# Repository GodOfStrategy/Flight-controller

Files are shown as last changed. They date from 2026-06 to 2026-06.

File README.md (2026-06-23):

# Flight-controller
A custom Flight controller to control a rocket with TVC! It uses a STM32 and other peripherals like power management, battery charging etc. to make it a fully functional controller, with LiPo support.
This is my schematic{1A992728-89DA-410E-9264-2D571C69BAF3}
This is how my PCB looks:{BEE2E16C-D04B-4341-9590-978375379D45}
This how my Assembled PCB is supposed to look like:{85D26635-DA95-49A9-963A-9BCFD05A4956}
{B8652330-A4F8-4AD3-A79F-0697AFAC499F}
This is my BoM (also in a .csv file in the repo): 
[bom.csv](https://github.com/user-attachments/files/29258043/bom.csv)

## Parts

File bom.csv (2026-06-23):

Designator | Footprint | Value |  | Generic-Name | Qty | Source | Total Price ($) | Product link
C1 | 0402 | 47 nF |  | Capacitors | 20 | 20 JLCPCB | 0.068 | https://jlcpcb.com/partdetail/83376-0402B473K500NT/C82219
C2,C3 | 0402 | 22 uF |  |  | 20 | 20 JLCPCB | 0.394 | https://jlcpcb.com/partdetail/16204-CL05A106MQ5NUNC/C15525
C4 | 0805 | 10 uf |  |  | 5 | 5 JLCPCB | 1.0915 | https://jlcpcb.com/partdetail/125403-GRM21BR61A476ME15L/C124129
C10,C11,C16,C17,C9 | 0805 | 100 nF |  |  | 18 | 18 JLCPCB | 2.1114 | https://jlcpcb.com/partdetail/46786-CL21A226MAQNNNE/C45783
C12,C13,C14,C5,C8 | 0805 | 10 uF |  |  | 10 | 10 JLCPCB | 0.912 | https://jlcpcb.com/partdetail/439567-GRM21BR61H106KE43L/C440198
C15,C18,C19,C20,C21,C26,C28,C29,C30,C31,C32,C7 | 0402 | 20 pF |  |  | 34 | 34 JLCPCB | 0.204 | https://jlcpcb.com/partdetail/1877-CL05B104KO5NNNC/C1525
C22,C23 | 0402 | 6.8 pF |  |  | 20 | 20 JLCPCB | 0.066 | https://jlcpcb.com/partdetail/1906-0402CG200J500NT/C1554
C24,C25 | 0402 | 2.2 uF |  |  | 20 | 20 JLCPCB | 0.048 | https://jlcpcb.com/partdetail/1928-0402CG6R8C500NT/C1576
C27 | 0402 | 1 uF |  |  | 20 | 20 JLCPCB | 0.154 | https://jlcpcb.com/partdetail/13164-CL05A225MQ5NSNC/C12530
C33,C34,C35,C36,C6 | 0402 | 44 uF |  |  | 20 | 20 JLCPCB | 0.282 | https://jlcpcb.com/partdetail/53938-CL05A105KA5NQNC/C52923
CARD1 | SMD | TF-01A | C91145 | SD Card Slot | 2 | 2 JLCPCB | 0.3802 | https://jlcpcb.com/partdetail/Korean_HropartsElec-TF01A/C91145
D1 | 0805 | LED |  | LED | 20 | 20 JLCPCB | 0.244 | https://jlcpcb.com/partdetail/Hubei_KENTOElec-KT0805B/C2293
J1 | 插件,P=2.54mm | Screw_Terminal_01x02 |  | Screw Terminal | 2 | 2 JLCPCB | 0.48 | https://jlcpcb.com/partdetail/Ningbo_Xinlaiya_Elec-XY308_2_542P/C557685
L1 | 1210 | 1 uH |  |  | 6 | 6 JLCPCB | 0.696 | https://jlcpcb.com/partdetail/100626-CMI322513U1R0KT/C99412
L2 | 1008 | 1.5 uH |  | Inductors | 6 | 6 JLCPCB | 0.2256 | https://jlcpcb.com/partdetail/XR-XRNR252010_1_5uHN/C5289259
L3 | 1210 | 5.6uH |  |  | 6 | 6 JLCPCB | 0.2748 | https://jlcpcb.com/partdetail/TDK-NLV32T_5R6JPF/C87563
L4 | 0603 | FCM1608KF-601T03 | C141723 | Ferrite Bead | 20 | 20 JLCPCB | 0.202 | https://jlcpcb.com/partdetail/TAITECH-FCM1608KF601T03/C141723
R1,R2 | 0402 | 5.1K |  | Resistors | 20 | 20 JLCPCB | 0.018 | https://jlcpcb.com/partdetail/26648-0402WGF5101TCE/C25905
R9 | 0201 | 30.1K |  |  | 20 | 20 JLCPCB | 0.012 | https://jlcpcb.com/partdetail/301723-RC01W3012FT/C320818
R10 | 0201 | 383 |  |  | 20 | 20 JLCPCB | 0.012 | https://jlcpcb.com/partdetail/416501-0201WMF3830TEE/C423551
R11 | 0201 | 5.23K |  |  | 20 | 20 JLCPCB | 0.022 | https://jlcpcb.com/partdetail/RALEC-RTT015231FTH/C332546
R12,R13,R16,R17,R18,R19,R20,R21,R22,R3,R4,R5,R6,R7,R8 | 0201 | 10K |  |  | 40 | 40 JLCPCB | 0.032 | https://jlcpcb.com/partdetail/FOJAN-FRC0201J103TS/C7467266
R14 | 0805 | 100K |  |  | 20 | 20 JLCPCB | 0.064 | https://jlcpcb.com/partdetail/160838-0805W8F1003T5E/C149504
R15 | 0201 | 22.1K |  |  | 20 | 20 JLCPCB | 0.02 | https://jlcpcb.com/partdetail/Walsin_TechCorp-WR02X2212FAL/C384418
SW1,SW2 | SMD,4x3mm | TS-1088-AR02016 |  | Switches | 8 | 8 JLCPCB | 0.4408 | https://jlcpcb.com/partdetail/XUNPU-TS_1088AR02016/C720477
U1 | VQFN-24-EP(4x4) | BQ25883RGER | C720477 | battery Management | 2 | 2 JLCPCB | 8.189 | https://jlcpcb.com/partdetail/TexasInstruments-BQ25883RGER/C544362
U2 | VQFN-15-HR(2.5x3) | TPS63070RNMR | C544362 | Buck convertor (5V) | 2 | 2 JLCPCB | 2.6384 | https://jlcpcb.com/partdetail/TexasInstruments-TPS63070RNMR/C109322
U3 | SOT-23-6-THIN(DDC) | LMR51430 | C109322 | Buck convertor | 2 | 2 JLCPCB | 1.73 | https://jlcpcb.com/partdetail/TexasInstruments-LMR51430YFDDCR/C5219261
U4 | LGA-10(2x2) | BMP580 |  | Barometer | 2 | 2 JLCPCB | 2.6674 | https://jlcpcb.com/partdetail/BoschSensortec-BMP580/C22391138
U5 | LGA-14(3x2.5) | ICM-45686 | C22391138 | IMU | 2 | 2 JLCPCB | 25.8362 | https://jlcpcb.com/partdetail/TDKInvenSense-ICM45686/C22459454
U6 | LQFP-64(10x10) | STM32F722RETx | C22459454 | MCU | 2 | 2 JLCPCB | 12.522 | https://jlcpcb.com/partdetail/STMicroelectronics-STM32F722RET6/C118207
USB1 | SMD | TYPE-C16PIN2MD |  | USB-C | 3 | 3 JLCPCB | 0.2205 | https://jlcpcb.com/partdetail/SHOUHAN-TYPE_C_16PIN_2MD_073/C2765186
X1 | SMD3225-4P | X322525MOB4SI | C2765186 | 25 MHz Quartz Crystal | 6 | 6 JLCPCB | 0.618 | https://jlcpcb.com/partdetail/YXC_CrystalOscillators-X322525MOB4SI/C9006
X2 | SMD3215-2P | Q13FC1350000400 | C9006 | 32.768 KHz Quartz Crystal | 5 | 5 JLCPCB | 0.8635 | https://jlcpcb.com/partdetail/SeikoEpson-Q13FC13500004/C32346

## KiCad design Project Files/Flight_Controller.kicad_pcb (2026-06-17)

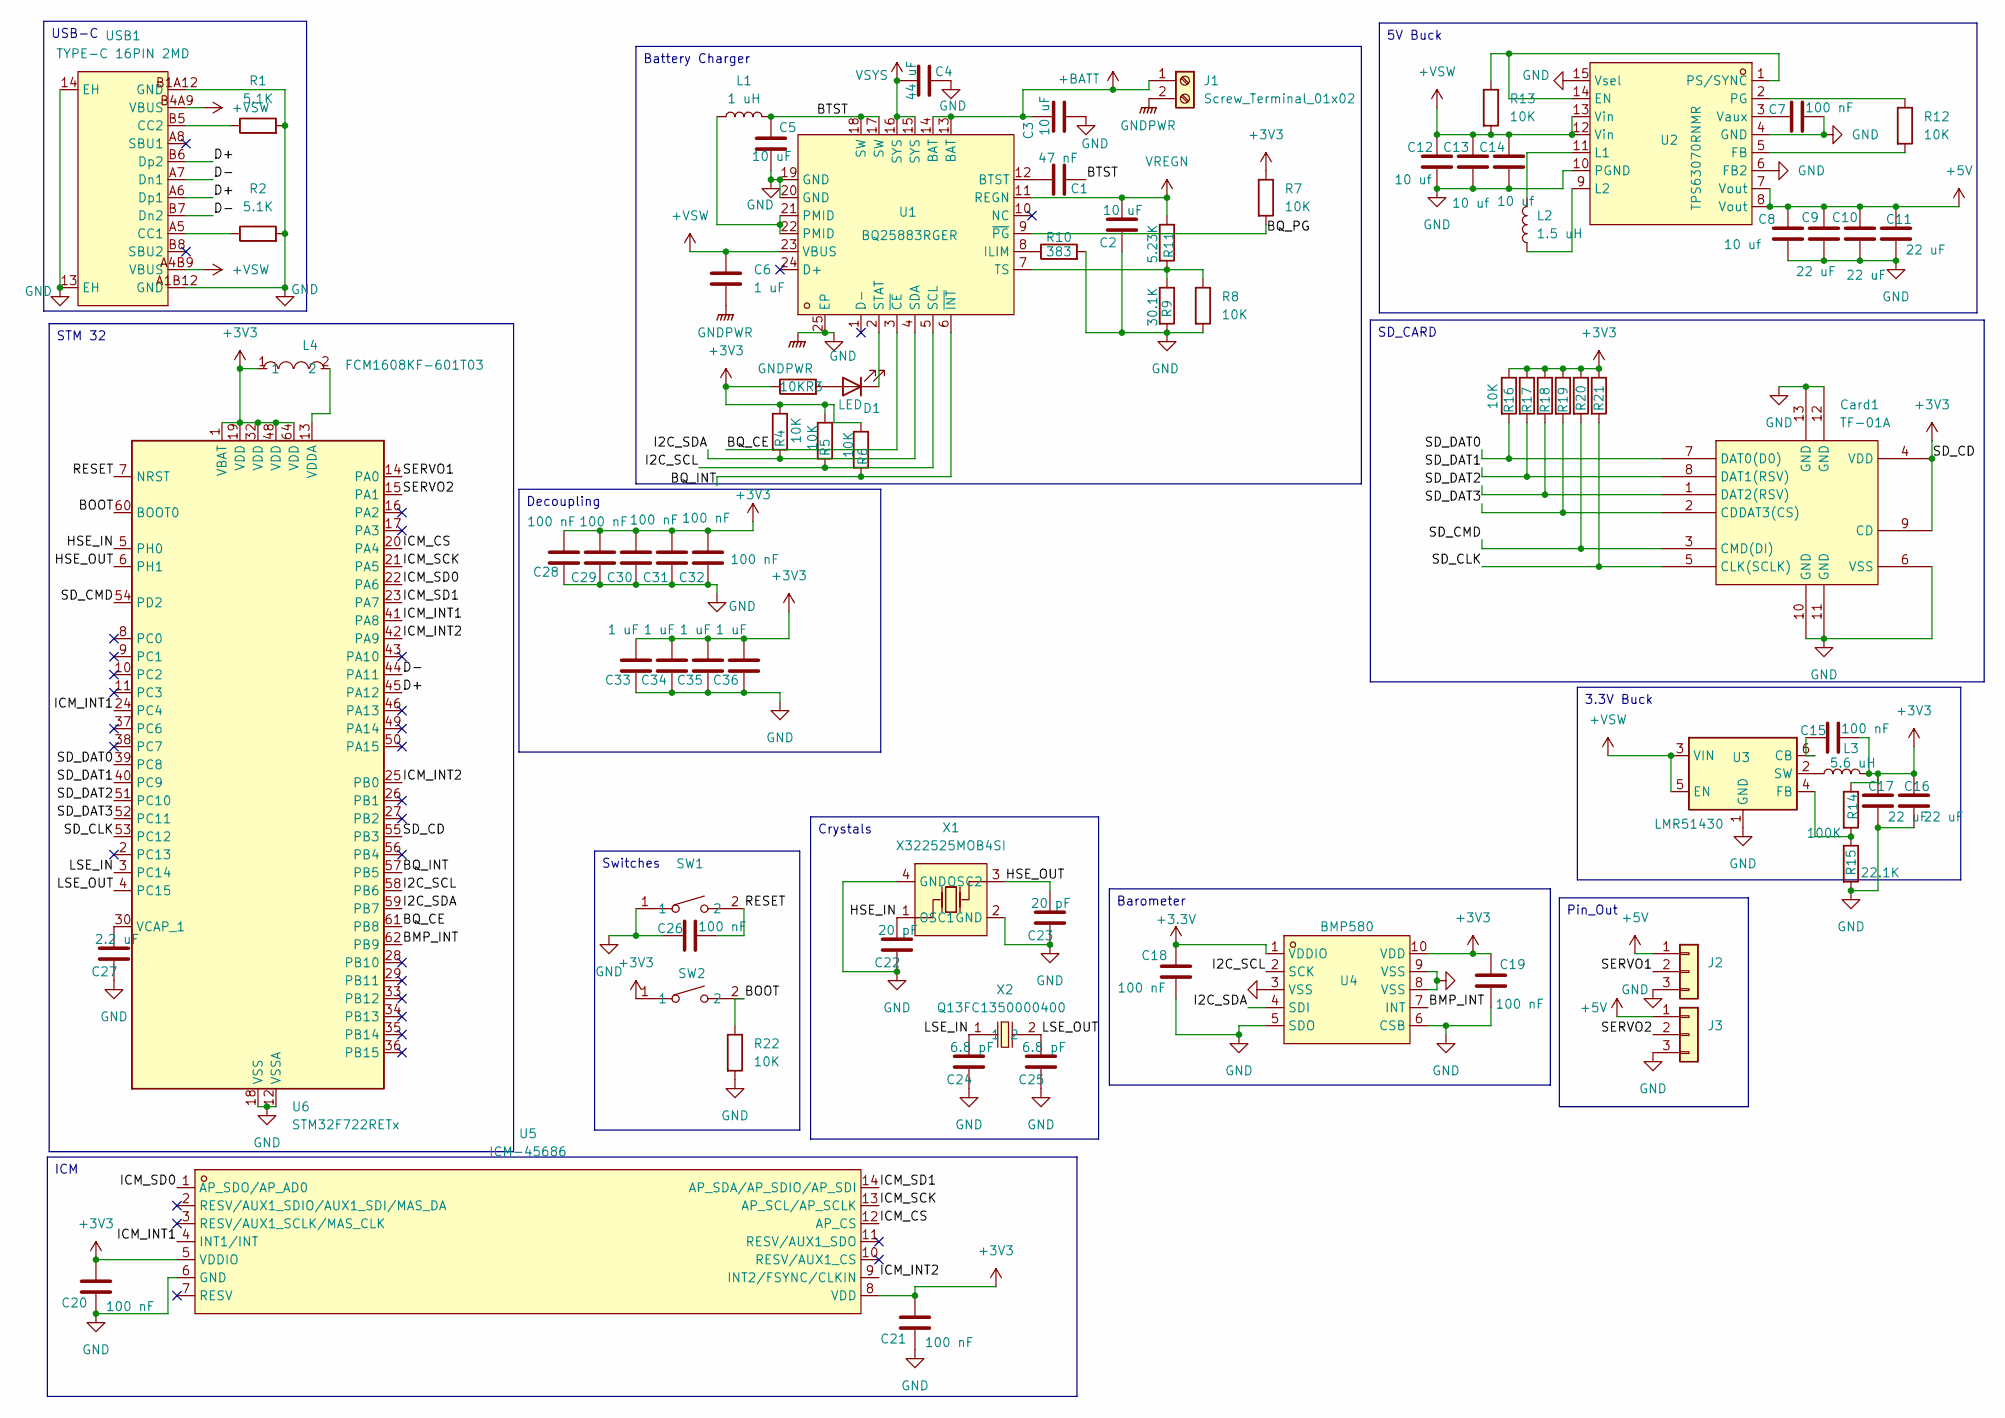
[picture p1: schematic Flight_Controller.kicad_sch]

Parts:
C1: 47 nF; C_0402_1005Metric
C2, C3: 10 uF; C_0402_1005Metric
C4: 44 uF; C_0805_2012Metric
C5: 10 uF; C_0805_2012Metric
C6, C33, C34, C35, C36: 1 uF; C_0402_1005Metric
C7, C15, C18, C19, C20, C21, C26, C28, C29, C30, C31, C32: 100 nF; C_0402_1005Metric
C8, C12, C13, C14: 10 uf; C_0805_2012Metric
C9, C10, C11, C16, C17: 22 uF; C_0805_2012Metric
C22, C23: 20 pF; C_0402_1005Metric
C24, C25: 6.8 pF; C_0402_1005Metric
C27: 2.2 uF; C_0402_1005Metric
Card1: TF-01A; TF-SMD_TF-01A; MPN TF-01A; LCSC Part C91145
D1: LED; LED_0805_2012Metric
J1: Screw_Terminal_01x02; TerminalBlock_Xinya_XY308-2.54-2P_1x02_P2.54mm_Horizontal
J2, J3: Conn_01x03; PinHeader_1x03_P2.54mm_Vertical
L1: 1 uH; L_1210_3225Metric
L2: 1.5 uH; L_1210_3225Metric
L3: 5.6 uH; L_1210_3225Metric
L4: FCM1608KF-601T03; L0603; MPN FCM1608KF-601T03; LCSC Part C141723
R1, R2: 5.1K; R_0402_1005Metric
R3, R4, R5, R6, R7, R8, R12, R13, R16, R17, R18, R19, R20, R21, R22: 10K; R_0201_0603Metric
R9: 30.1K; R_0201_0603Metric
R10: 383; R_0201_0603Metric
R11: 5.23K; R_0201_0603Metric
R14: 100K; R_0805_2012Metric
R15: 22.1K; R_0201_0603Metric
SW1, SW2: TS-1088-AR02016; SW-SMD_L3.9-W3.0-P4.45; MPN TS-1088-AR02016; LCSC Part C720477
U1: BQ25883RGER; VFQFPN-24_L4.0-W4.0-P0.50-BL-EP2.8; MPN BQ25883RGER; LCSC Part C544362
U2: TPS63070RNMR; VQFN-15_L3.0-W2.5-P0.50-BL; MPN TPS63070RNMR; LCSC Part C109322
U3: LMR51430; SOT-23-6
U4: BMP580; LGA-10_L2.0-W2.0-P0.50-TL_BMP580; MPN BMP580; LCSC Part C22391138
U5: ICM-45686; LGA-14_L3.0-W2.5-P0.50-TL; MPN ICM-45686; LCSC Part C22459454
U6: STM32F722RETx; LQFP-64_10x10mm_P0.5mm
USB1: TYPE-C 16PIN 2MD; USB-C-SMD_TYPE-C-16PIN-2MD-073; MPN TYPE-C 16PIN 2MD(073); LCSC Part C2765186
X1: X322525MOB4SI; CRYSTAL-SMD_4P-L3.2-W2.5-BL; MPN X322525MOB4SI; LCSC Part C9006
X2: Q13FC1350000400; FC-135R_L3.2-W1.5; MPN Q13FC13500004; LCSC Part C32346

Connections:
+3.3V: C18.2, U4.1 (VDDIO)
+3V3: C15.1, C16.1, C17.1, C19.1, C20.1, C21.1, C28.1, C29.1, C30.1, C31.1, C32.1, C33.1, C34.1, C35.1, C36.1, Card1.4 (VDD), Card1.9 (CD), L3.2, L4.1, R3.1, R4.1, R5.1, R6.1, R7.1, R14.1, R16.1, R17.1, R18.1, R19.1, R20.1, R21.1, SW2.1, U4.10 (VDD), U5.5 (VDDIO), U5.8 (VDD), U6.1 (VBAT), U6.19 (VDD), U6.32 (VDD), U6.48 (VDD), U6.55 (PB3), U6.64 (VDD)
+5V: C8.1, C9.1, C10.1, C11.1, J2.1, J3.1, U2.7 (Vout), U2.8 (Vout)
+BATT: C3.1, J1.1, U1.13 (BAT), U1.14 (BAT)
+VSW: C6.1, C12.1, C13.1, C14.1, R13.2, U1.23 (VBUS), U2.12 (Vin), U2.13 (Vin), U3.3 (VIN), U3.5 (EN), USB1.A4B9 (VBUS), USB1.B4A9 (VBUS)
/BMP_INT: U4.7 (INT), U6.62 (PB9)
/BOOT: R22.1, SW2.2, U6.60 (BOOT0)
/BQ_CE: U1.3 (~CE), U6.61 (PB8)
/BQ_INT: R6.2, U1.6 (~INT), U6.57 (PB5)
/BQ_PG: R7.2, U1.9 (~PG)
/BTST: C1.1, C5.1, L1.2, U1.17 (SW), U1.18 (SW)
/D+: U6.45 (PA12), USB1.A6 (Dp1), USB1.B6 (Dp2)
/D-: U6.44 (PA11), USB1.A7 (Dn1), USB1.B7 (Dn2)
/HSE_IN: C22.1, U6.5 (PH0), X1.1 (OSC1)
/HSE_OUT: C23.1, U6.6 (PH1), X1.3 (OSC2)
/I2C_SCL: R5.2, U1.5 (SCL), U4.2 (SCK), U6.58 (PB6)
/I2C_SDA: R4.2, U1.4 (SDA), U4.4 (SDI), U6.59 (PB7)
/ICM_CS: U5.12 (AP_CS), U6.20 (PA4)
/ICM_INT1: U5.4 (INT1/INT), U6.24 (PC4), U6.41 (PA8)
/ICM_INT2: U5.9 (INT2/FSYNC/CLKIN), U6.25 (PB0), U6.42 (PA9)
/ICM_SCK: U5.13 (AP_SCL/AP_SCLK), U6.21 (PA5)
/ICM_SD0: U5.1 (AP_SDO/AP_AD0), U6.22 (PA6)
/ICM_SD1: U5.14 (AP_SDA/AP_SDIO/AP_SDI), U6.23 (PA7)
/LSE_IN: C24.1, U6.3 (PC14), X2.1
/LSE_OUT: C25.1, U6.4 (PC15), X2.2
/RESET: C26.1, SW1.2, U6.7 (NRST)
/SD_CLK: Card1.5 (CLK(SCLK)), R21.2, U6.53 (PC12)
/SD_CMD: Card1.3 (CMD(DI)), R20.2, U6.54 (PD2)
/SD_DAT0: Card1.7 (DAT0(D0)), R16.2, U6.39 (PC8)
/SD_DAT1: Card1.8 (DAT1(RSV)), R17.2, U6.40 (PC9)
/SD_DAT2: Card1.1 (DAT2(RSV)), R18.2, U6.51 (PC10)
/SD_DAT3: Card1.2 (CDDAT3(CS)), R19.2, U6.52 (PC11)
/SERVO1: J2.2, U6.14 (PA0)
/SERVO2: J3.2, U6.15 (PA1)
GND: C2.2, C3.2, C4.2, C5.2, C6.2, C7.1, C8.2, C9.2, C10.2, C11.2, C12.2, C13.2, C14.2, C16.2, C17.2, C18.1, C19.2, C20.2, C21.2, C22.2, C23.2, C24.2, C25.2, C26.2, C27.2, C28.2, C29.2, C30.2, C31.2, C32.2, C33.2, C34.2, C35.2, C36.2, Card1.6 (VSS), Card1.10 (GND), Card1.11 (GND), Card1.12 (GND), Card1.13 (GND), J1.2, J2.3, J3.3, R1.2, R2.2, R8.2, R9.2, R10.2, R15.2, R22.2, SW1.1, U1.19 (GND), U1.20 (GND), U1.25 (EP), U2.4 (GND), U2.6 (FB2), U2.10 (PGND), U2.15 (Vsel), U3.1 (GND), U4.3 (VSS), U4.5 (SDO), U4.6 (CSB), U4.8 (VSS), U4.9 (VSS), U5.6 (GND), U6.12 (VSSA), U6.18 (VSS), U6.31 (VSS), U6.47 (VSS), U6.63 (VSS), USB1.13 (EH), USB1.14 (EH), USB1.A1B12 (GND), USB1.B1A12 (GND), X1.2 (GND), X1.4 (GND)
unnamed: D1.2 (A), R3.2
unnamed: D1.1 (K), U1.2 (STAT)
unnamed: L1.1, U1.21 (PMID), U1.22 (PMID)
unnamed: C1.2, U1.12 (BTST)
unnamed: R10.1, U1.8 (ILIM)
unnamed: R8.1, R9.1, R11.2, U1.7 (TS)
unnamed: R13.1, U2.1 (PS/SYNC), U2.14 (EN)
unnamed: R12.2, U2.5 (FB)
unnamed: L2.2, U2.11 (L1)
unnamed: L2.1, U2.9 (L2)
unnamed: R12.1, U2.2 (PG)
unnamed: C7.2, U2.3 (Vaux)
unnamed: C15.2, U3.6 (CB)
unnamed: R14.2, R15.1, U3.4 (FB)
unnamed: L3.1, U3.2 (SW)
unnamed: C27.1, U6.30 (VCAP_1)
unnamed: L4.2, U6.13 (VDDA)
unnamed: R2.1, USB1.A5 (CC1)
unnamed: R1.1, USB1.B5 (CC2)
VREGN: C2.1, R11.1, U1.11 (REGN)
VSYS: C4.1, U1.15 (SYS), U1.16 (SYS)

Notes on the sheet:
5V Buck
Barometer
SD_CARD
3.3V Buck
ICM
Switches
STM 32
USB-C
Battery Charger
Decoupling
Crystals
Pin_Out

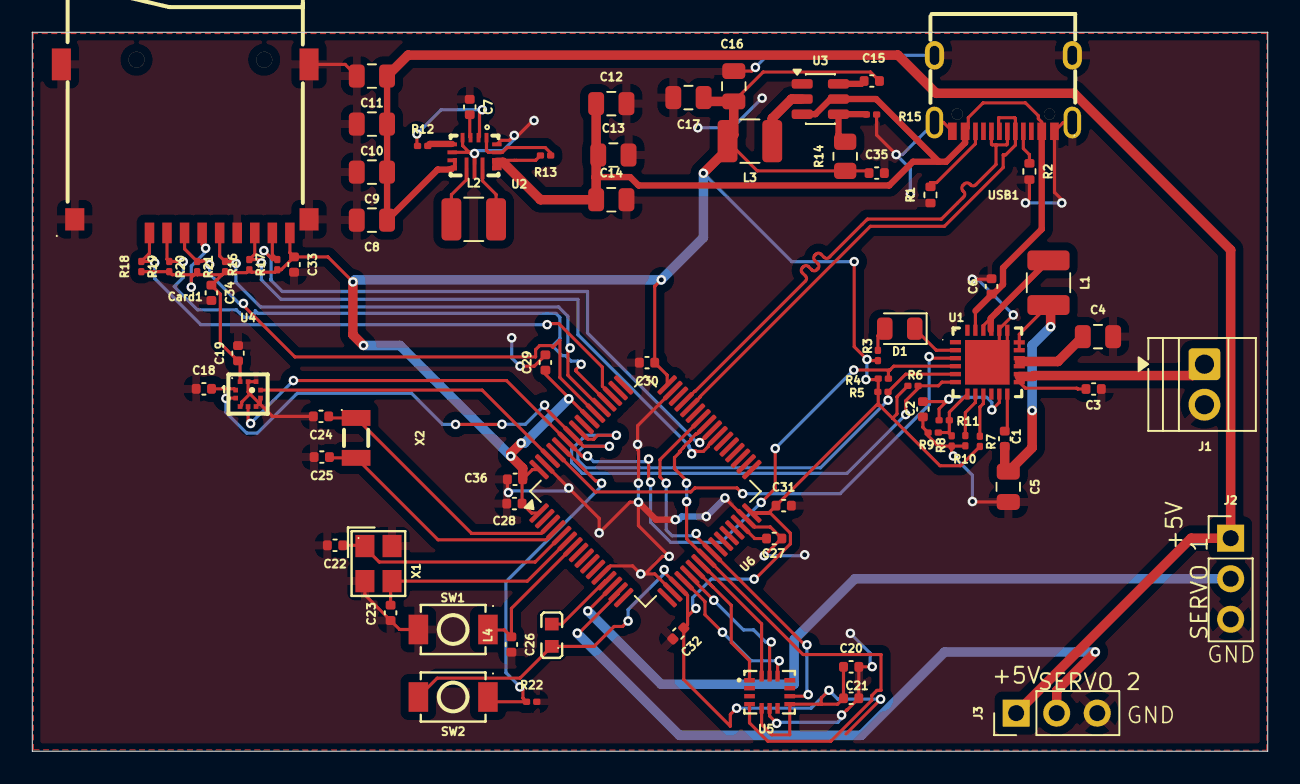
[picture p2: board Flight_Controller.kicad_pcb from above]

Board: 2 copper layers, 77.4 x 45.1 mm, 78 parts (0 on the bottom side), 56 nets.

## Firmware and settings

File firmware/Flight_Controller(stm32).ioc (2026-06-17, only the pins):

Mcu.UserName=STM32F722RETx
PA0-WKUP.Signal=S_TIM2_CH1_ETR
PA1.Signal=S_TIM2_CH2
PA11.Signal=USB_OTG_FS_DM
PA12.Signal=USB_OTG_FS_DP
PA4.Signal=SPI1_NSS
PA5.Signal=SPI1_SCK
PA6.Signal=SPI1_MISO
PA7.Signal=SPI1_MOSI
PB0.Signal=GPXTI0
PB3.Signal=GPIO_Input
PB5.Signal=GPXTI5
PB6.Signal=I2C1_SCL
PB7.Signal=I2C1_SDA
PB8.Signal=GPIO_Output
PC10.Signal=SDMMC1_D2
PC11.Signal=SDMMC1_D3
PC12.Signal=SDMMC1_CK
PC14-OSC32_IN.Signal=RCC_OSC32_IN
PC15-OSC32_OUT.Signal=RCC_OSC32_OUT
PC4.Signal=GPXTI4
PC8.Signal=SDMMC1_D0
PC9.Signal=SDMMC1_D1
PD2.Signal=SDMMC1_CMD
PH0-OSC_IN.Signal=RCC_OSC_IN
PH1-OSC_OUT.Signal=RCC_OSC_OUT
